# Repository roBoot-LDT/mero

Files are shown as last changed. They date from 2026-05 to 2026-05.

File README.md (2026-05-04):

# mero

A 45-day discipline project: build a remotely-controlled tracked/wheeled robot that finds 3 QR codes in camera view less than 2 minutes on uneven terrain

**Author:** Maksim Nemkov
**Started:** 2026-05-04
**Hard deadline:** 2026-06-17 (45 days)

---

## Why this project exists

This repository is not primarily a robotics project. It is a discipline experiment.

The goal is to complete one self-initiated technical project from start to finish, on time, with a publicly visible result. The robot is the medium, not the message. The message is: "I can finish what I start"

For three years prior to this project, no voluntary technical project was completed. This is the attempt to break that pattern. The project is intentionally constrained in scope so that the binding constraint is follow-through, not technical capability.

---

## What the robot does (Definition of Done)

A wheeled robot that:

1. Is controlled remotely over BLE from a custom 5-button pad (4 directions + start/stop).
2. Carries an ESP32-CAM that streams video over WiFi to a server.
3. The server detects QR codes in the video stream using OpenCV in real time.
4. The operator drives the robot on uneven terrain so that a pre-placed 3 QR codes must be founded and be inside the camera frame less than 2 minutes.

**The project is considered done when:**

- 5 out of 10 attempts succeed at founding the 3 QRs in frame less than 2 minutes on a defined uneven surface.
- All 10 attempts are recorded on video and published in this repository.
- A final write-up exists in `docs/postmortem.md` covering what worked, what didn't, what the next iteration would change.

**Not in scope for v1 (these belong to v2 if there ever is one):**

- Camera gimbal with servo stabilization
- Autonomous QR search
- Autonomous driving
- Obstacle avoidance
- Battery telemetry, OTA updates, app GUI

If during the 45 days the temptation arises to add any of the above, the rule is: **note it in `IDEAS.md` and do not implement it.**

---

## Architecture

Three independent nodes, intentionally separated to avoid one ESP32 trying to do everything.

```
+---------------------+        BLE 5         +-----------------------+
|  REMOTE             | <==================> |  ROBOT MAIN           |
|  ESP32 dev board    |                      |  ESP32-S3-N16R8       |
|  5 tactile buttons  |                      |  motor driver         |
|                     |                      |  (TB6612FNG / DRV8833)|
+---------------------+                      |  2x DC motors         |
                                             |  2x 18650 + BMS 2S    |
                                             |  buck 5V              |
                                             +-----------+-----------+
                                                         |
                                                         | WiFi (same AP)
                                                         |
                                             +-----------v-----------+
                                             |  ESP32-CAM            |
                                             |  MJPEG stream / HTTP  |
                                             +-----------+-----------+
                                                         |
                                                         | WiFi
                                                         |
                                             +-----------v-----------+
                                             |  SERVER (laptop or VPS)|
                                             |  Python + OpenCV       |
                                             |  pyzbar / cv2.QRCode   |
                                             |  publishes detection   |
                                             |  events                |
                                             +------------------------+
```

**Why three nodes and not one:** a single ESP32-CAM cannot reliably run BLE + WiFi + camera + motor PWM at the same time. It has too few free GPIOs after the camera takes its pins, and BLE/WiFi share the radio. Splitting responsibilities makes each node simpler and debuggable in isolation.

**Why the server and not on-device QR detection:** ESP32-CAM can do QR detection locally (`esp32-camera` + `quirc` works), but routing detection to a Python server gives a cleaner debugging surface, easier logging, and faster iteration on detection parameters during the 45 days. After the project is done, on-device detection is a candidate for v2.

---

## Hardware

| Component | Notes |
|---|---|
| ESP32-S3-N16R8 dev board | Robot main controller. BLE 5 + WiFi 4. |
| ESP32 (any DevKit) | Remote control unit. |
| ESP32-CAM | Video streaming over WiFi. |
| TB6612FNG or DRV8833 | Motor driver. **Not L293D** — it cannot handle the stall current of these motors. |
| 2x DC motors (RS-385 class, 5V nominal) | Drive motors. |
| 2x 18650 Li-Ion cells + 2S BMS | Robot power. ~7.4V nominal. |
| MP1584 or LM2596 buck converter | Steps 7.4V down to 5V for ESP32 / driver logic. |
| 5x tactile buttons + pull-ups | Remote keypad. |
| Wheels (printed) | Diameter ≥ 80 mm, otherwise robot is geared too fast. |
| 3D printer (Bambu Lab P1S) | Chassis, mounts, wheels. |
| Multimeter, soldering iron, lab PSU | Already on hand. |

**Critical caveats discovered before start:**

- ESP32-S3 supports BLE 5 only, **not** classic Bluetooth. The remote must speak BLE GATT.
- L293D is too weak for these motors and will burn out under stall load. Replaced with TB6612FNG / DRV8833.
- Bare DC motors without gearing rev too fast (5–15k RPM) and have low torque at low speed — large wheels or geared replacements are required for terrain.
- Two 18650 in series is 7.4V. Connecting that directly to a 3.3V or 5V logic input destroys the board. A buck converter is mandatory.

---

Long-form notes live in Obsidian. What lands in `docs/devlog.md` is the public summary, written at least once per week.

---

## Milestones

Three checkpoints. Each has a measurable, video-verifiable state. Missing a checkpoint by more than 3 days triggers a written re-plan in `docs/milestones.md`, not a silent slip.

### M1 — 2026-05-18 (day 15): bench integration

- Chassis printed and assembled (motors mounted, wheels on, can be held in hand).
- ESP32-S3 drives both motors forward / back / left / right via TB6612FNG over USB-serial commands. No BLE yet.
- ESP32-CAM streams MJPEG to laptop over WiFi.
- Python server pulls stream, runs `cv2.QRCodeDetector` (or `pyzbar`), logs `qr_seen=True/False` per frame.
- Video evidence: 30 seconds showing motors responding, stream live, QR detection logged.

### M2 — 2026-06-01 (day 30): wireless robot

- BLE remote control works. Robot drives untethered.
- Robot runs from 18650 + BMS + buck. No bench PSU.
- Video stream survives motion. QR detection still works on a moving feed.
- Robot drives reliably on flat indoor surface.
- Video evidence: 2 minutes of free driving, QR detected on the move.

### M3 — 2026-06-17 (day 45): final challenge

- Defined uneven test surface (photographed, dimensioned).
- 10 attempts at the 2-minute QR-hold task. All recorded.
- Postmortem written.
- README updated with results — pass or fail honestly.

If M3 succeeds: project is done.
If M3 fails: the project is **still done.** A failed-but-finished project beats an abandoned one. A failed run still gets written up and committed.

## License

MIT. See `LICENSE`.

---

## Contact

This is a solo project. Issues and PRs are not expected, but the repository is public so that finishing the project is a publicly visible commitment.

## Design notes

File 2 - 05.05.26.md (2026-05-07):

Начал собирать схему - спаял коннекторы к движкам, подсоединил их к плате l298n, подключил батарейный отсек. Соединил проводами по datasheet esp32 и l298n для управления движками. 
Спаял с флюсом и припоем (движки) - поверх добавил термоклея для надежности.
Плату esp32 буду питать от лабораторника.
Важное уточнение - на данный момент блок с 18650 подключен напрямую и не имеет между собой схему со вчерашнего дня, к ней я перейду позже.
Дополнительно ко всему - загрузил программу для тестирования работы движков. Получилось успешно - итог 2го дня на видео [[day2_vid.MOV]].

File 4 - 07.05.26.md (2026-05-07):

Сегодня главная задача - подсоединить БП к электросхеме и создать платформу на которой будут находиться все компоненты.

Припаял MP1584 (регулятор напряжения), изначально выход был 5.7в, с помощью потенциометра на плате понизил до 5в.
Включил - работает. Видео [[day4_vid.MOV]]

На будущее - возможно при пайке контактов p+ p- hx-2s-d20 он включает свою защиту и приходится его "будить" обратной подачей напряжения.

DONE:
- MP1584 buck настроен на 5V, подтверждено мультиметром
- ESP32-S3 питается автономно от блока питания через MP1584
- L298N питается от P+/P− BMS (7.4V)
- Прошивка загружена, моторы выполняют цикл forward/back/left/right
- Первый автономный запуск без USB и лабораторного БП — работает

Спустя пару часов - сделал большой прогресс: подключил камеру esp32-cam, прошил с помощью pl2303 USB UART boada. Конечно пришлось попотеть чтобы банально "зафлэшить" софт на esp32 из-за особенностей платы (нужно замкнуть gnd i0) и потом еще потратить время чтобы понять: для первичного запуска софта нужно нажать кнопку hard reset... 
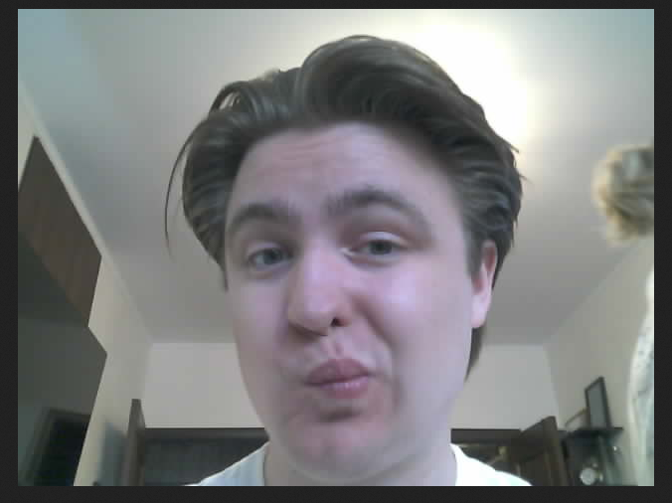
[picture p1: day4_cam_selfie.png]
По итогу - получилось сделать селфи: 

Далее - сделал так чтобы камера отсылала видеопоток на локальный сервер. Потом смогу обрабатывать видео и искать на нем Qr
Написал код для получения данных с сервера и сканирования на наличие qr.
Успех! Вот только не стабильно сканируется QR на камере, но надеюсь это поправимо

Сделаю коммит и пойду дальше - так как уже с точки зрения схемотехники все закончено (на роботе). Следующая задача - создать платформу на которой все будет крепиться и красиво распаять все это на плате
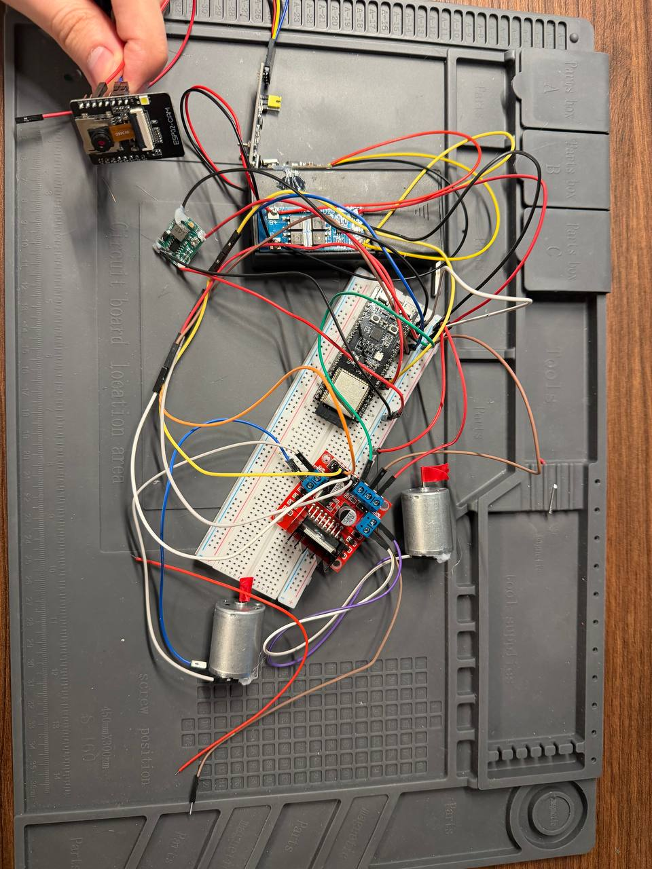
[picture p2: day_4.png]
Как это выглядит сейчас:

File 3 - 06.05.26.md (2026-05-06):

День 3. Сегодня я сделаю полноценно рабочий блок-питания для робота из:
- 2 банки 18650
- Регулятора зарядки\разрядки HX-2S-D20
- Регулятора зарядки с TYPE-C BMS 2S
- Корпуса для 2 банок
Соединил в единый компонент. В данный момент проверяю, все ли корректно. Подключил type-c и на LX-USC-V2 начал гореть светодиод, в видео где его использовали - было также. При отключении тумблера на холдере - светодиод начинает мигать. Надеюсь это признак "рабочисти" всей схемы. Замерил напряжение на p+ p- - 1.82в. Как-то очень мало для 2 новых банок и по идее это означает что они трупы. Но дам еще времени зарядиться и проверю напряжение вновь

DONE: 
- Собран блок питания: 2x18650 + HX-2S-D20 BMS + LX-USC-V2 зарядка 
- BMS сбрасывается подачей 8.5V на P+/P− от лабораторного БП 
- Выход P+/P−: 7.4V подтверждено мультиметром 
PROBLEMS:
- LX-USC-V2 нагрелся при первом подключении (термоклей расплавился) 
- BMS заблокировал выход при первом включении → сброс: 8.5V на P+/P− от лабораторного БП на 5-10 секунд
LEARNED: 
- BMS серии HX-2S разблокируется подачей зарядного напряжения на P+/P−

Доп - очень тяжело паялась клемма в холдере (для подключения BM), пришлось накрутить провод на клемму и зафиксировать термоклеем.

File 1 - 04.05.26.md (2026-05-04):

Начал составлять схему подключения всех компонентов
На этом этапе начал разбираться с работой каждого комплектующего: L298N, bms 2s, mp1584 и прочее
Около часа капался в datasheet'ах каждого элемента для корректного подключения (на бумаге)
В моменте проектирования стало понятно что просто использовать 2 банки 18650 напрямую в l298n и отдельную банку на контроллер esp32 - не логично, можно параллельно соединить и l298n и esp32, вот только при подаче напряжения 7,2V на esp32 - будет kaputt. Потому между ними добавляю mp1584 с выходом на 5В

Во время уточнения работы с 18650, с помощью BMS, оказалось что был куплен charging controller, а не charge/discharge. Докупил HX-2S-D20 - будет завтра. BMS 2S выбрасывать не буду, так как на плате есть usb type-c с помощью которого зарядка банок будет удобна. В электро-схему добавил уточнение в компоновку питания. Фото и набросок прикладываю.

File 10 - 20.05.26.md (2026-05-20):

День 10
Вчерашняя проблема с потерей подключения при нажатии любой кнопки - вылечена. 
Во время работы выяснилась другая проблема - при добавлении регулятора AMS1117 3.3V - плата работала не стабильно и банально не запускалась
Вероятнее всего проблема в падении напряжения при включении bluetooth. Эту закономерность смог отследить наличием светодиода состояния работы платы
Пробовал припаять параллельно 2 конденсатора на 20мкф суммарно, но не помогло...
По итогу удалил из цепи ams1117 и подключил питание напрямую в VIN. Заработало. 
Важное уточнение: во время одного из тестов пульт управления не запустился и была таже проблема что и ранее
Выключив и включив - проблема прошла. Возможное решение - добавить больший конденсатор.
Также инвертировал направление поворотов робота и перевернул камеру на 180
Задача на следующий день - отрегулировать плавность движения робота. И попробовать отсканировать QR в первый раз с помощью удаленного управления

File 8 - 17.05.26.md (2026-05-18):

День 8. Был большой перерыв между обновлениями - все никак не получалось соединить робота с контроллером по bluetooth. 
После печати 3д модели выявлены следующие нюансы:
 - Нужно переделать положение двигателей (сделать их ближе к корпусу)
 - Допуска в диаметре шин и колеса нужно уменьшить. Шина получилась неровной
 - Нужно каким-либо образом сделать автоцентрирование шины на колесе
 - Включение\выключение блока питания нужно вывести отдельно, в удобное место
 - Нужно выровнять колесо-роллер, чтобы робот был выровнен по горизонтали
 - Продумать отладку и подключение micro-usb к esp32s3 робота, когда плата уже подсоединена к корпусу
 - Повысить плату над корпусом, так как в данный момент ножки esp32s3 упираются в корпус
 - Требуется продумать регулировку уровня наклона платы камеры с помощью физического взаимодействия
 - Создать крышку для робота

Фото сборки в данный момент прилагаю:
![[day8_robot.png]]

Проблемы во время разработки:
 - Моторы не корректно работали, при одних и техже значениях - моторы крутятся по разному. Это оказалось из-за логики работы L298N. Прозвонил все пины ведущие к l298n и оказалось что 1 пин не пропаял, исправил и все получилось

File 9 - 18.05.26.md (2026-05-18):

День 9
За сегодняшний день собрал контроллер дистанционного управления роботом. Пайка занимает уйму времени. Помимо этого, конечно же, все работает не с первого раза. Сегодня не было исключения и к концу дня - у контроллера работает только кнопка "вперед". Оно и правильно - куда еще, если не вперед
Помимо этого при нажатии на кнопку вперед - контроллер сразу теряет связь с роботом...
Завтра буду решать эту проблему
И еще - припаял питание к esp32-cam. Факт на будущее - у этой платы нет светодиода уведомления о работе (потратил 20 минут времени на выяснение того, что плата уже работала)
Фото-отчет за сегодня:
![[day9_controller.png]]
![[day9_full_build.png]]

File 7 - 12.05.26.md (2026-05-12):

День 7. Чутка доделал 3д модель и отправил на печать. 6 часов заняла печать сразу:
- корпуса
- 2 держателей двигателя
- 2 диска
На удивление получилось хорошо. Нужно будет отредактировать напильником или гравером, но лишь 1мм у держателя двигателя. Во всем остальном пока подходит.
![[day7_printables.png]]
Завтра подсоединю электросхему, закреплю двигатели, батарею и поставлю на печать шины

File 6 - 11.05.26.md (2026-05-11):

Сегодня сделал 3д модель:
- Несущего корпуса
- Держателей двигателей
- Шины
- Резины
- Двигателей
- Ролика
Заранее предусмотрел крепежные отверстия вместе с отверстиями для проводов. Завтра чуть отредактирую скругления и начну печатать. 
![[day6_assembly.png]]

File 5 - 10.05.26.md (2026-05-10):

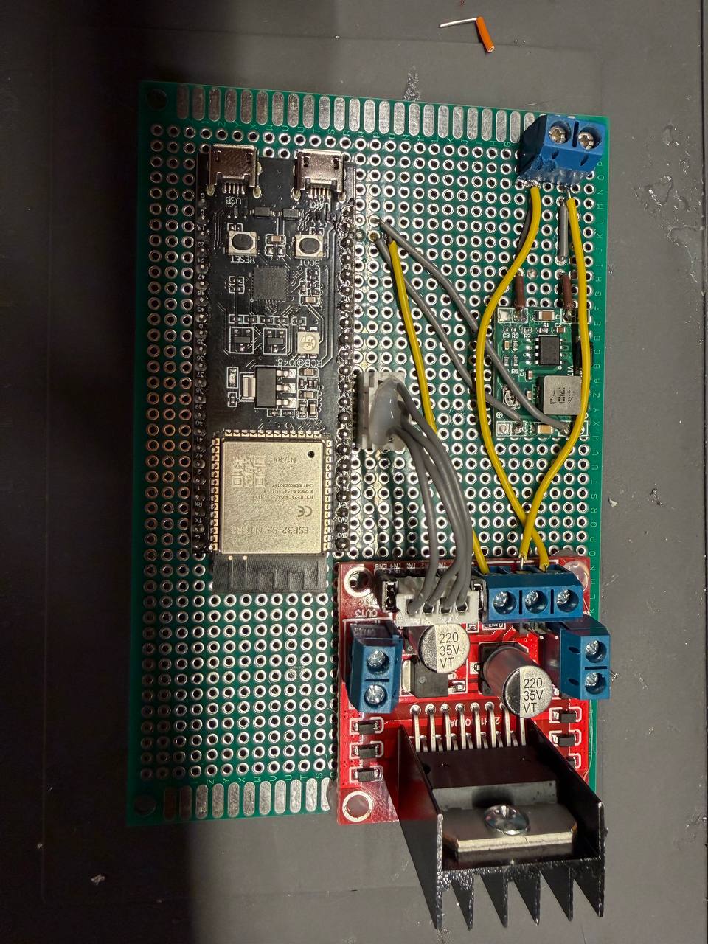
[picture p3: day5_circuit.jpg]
За сегодняшний день (после Майских праздников) я смог улучшить мою схему вместе в моторами. Распаял все компоненты на зеленой платформе с новыми коммутациями и удобным подключением. Это заняло очень много времени и я надеюсь это стоило того. Ну и в конце-концов это работает: 

![[day5_circuit2.png]]

Также про двигатели - нашел в закромах старые движки с древнего проекта. Это абсолютно такие-же двигатели как и были, только с редуктором. Взял их, припаял провода, укрепил термоусадкой.
Я доволен проделанной работой.
Завтра начну делать 3д модель корпуса. Заранее размышляю о механической регулировке угла наклона камеры.

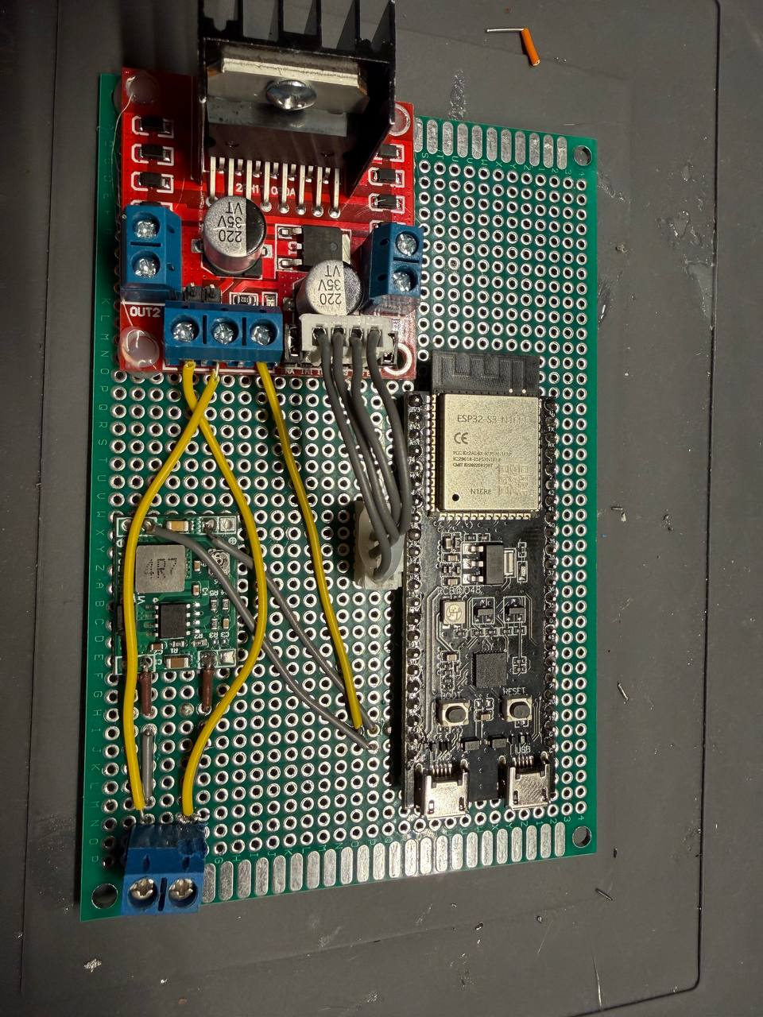
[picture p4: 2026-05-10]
day5_circuit2.png

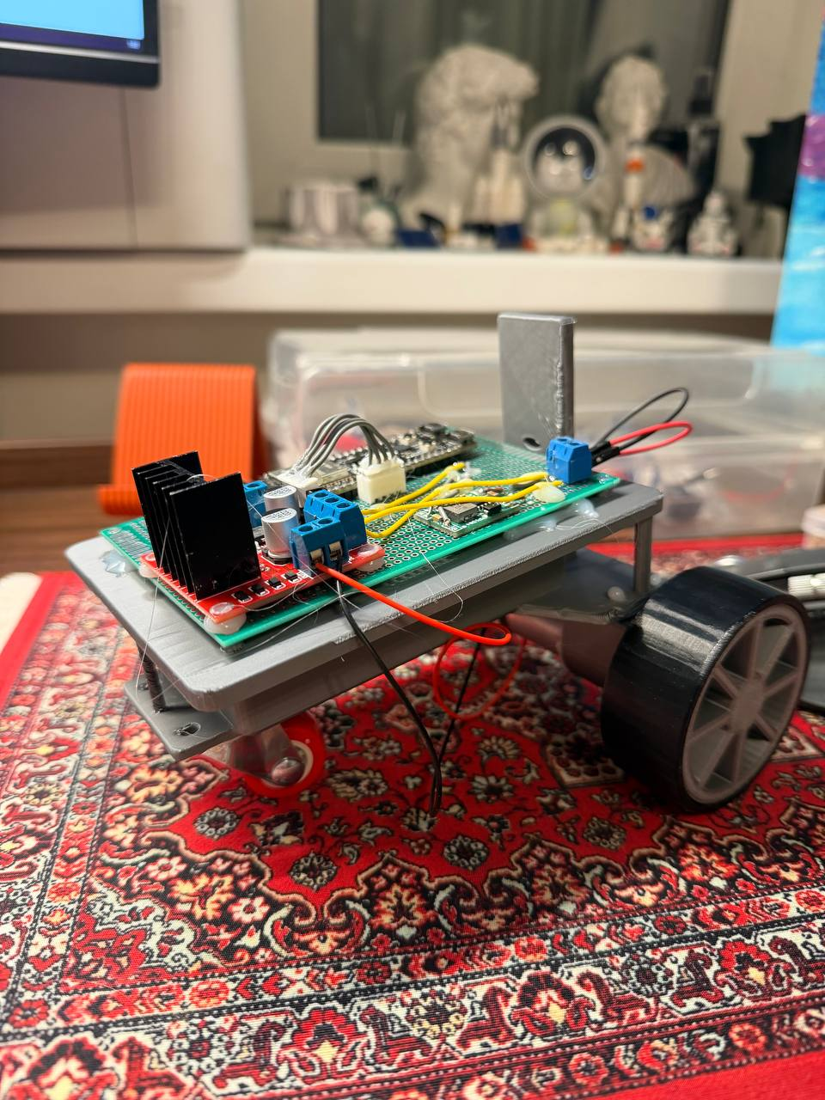
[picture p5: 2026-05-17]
day8_robot.png

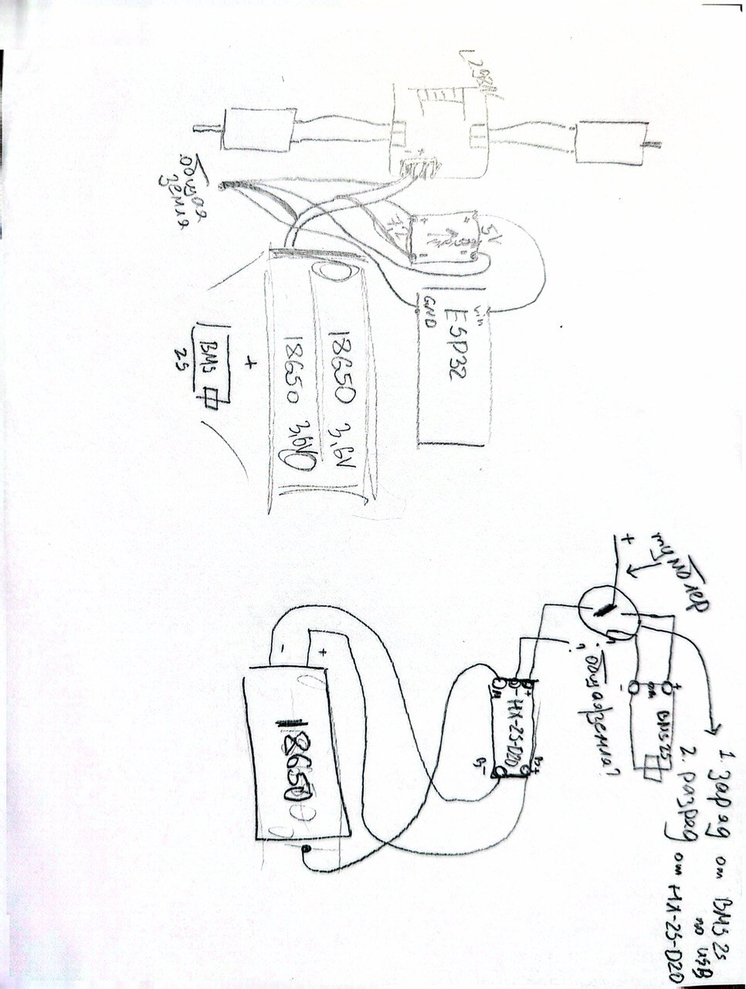
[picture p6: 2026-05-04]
image.png

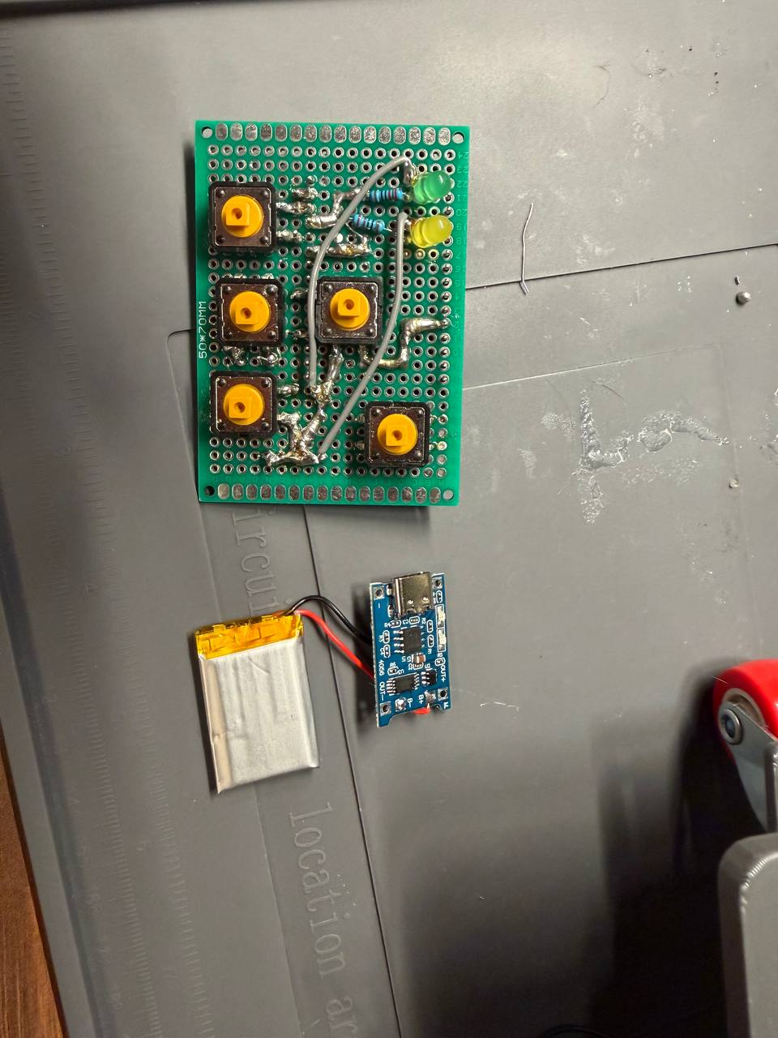
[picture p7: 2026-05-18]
day9_controller.png

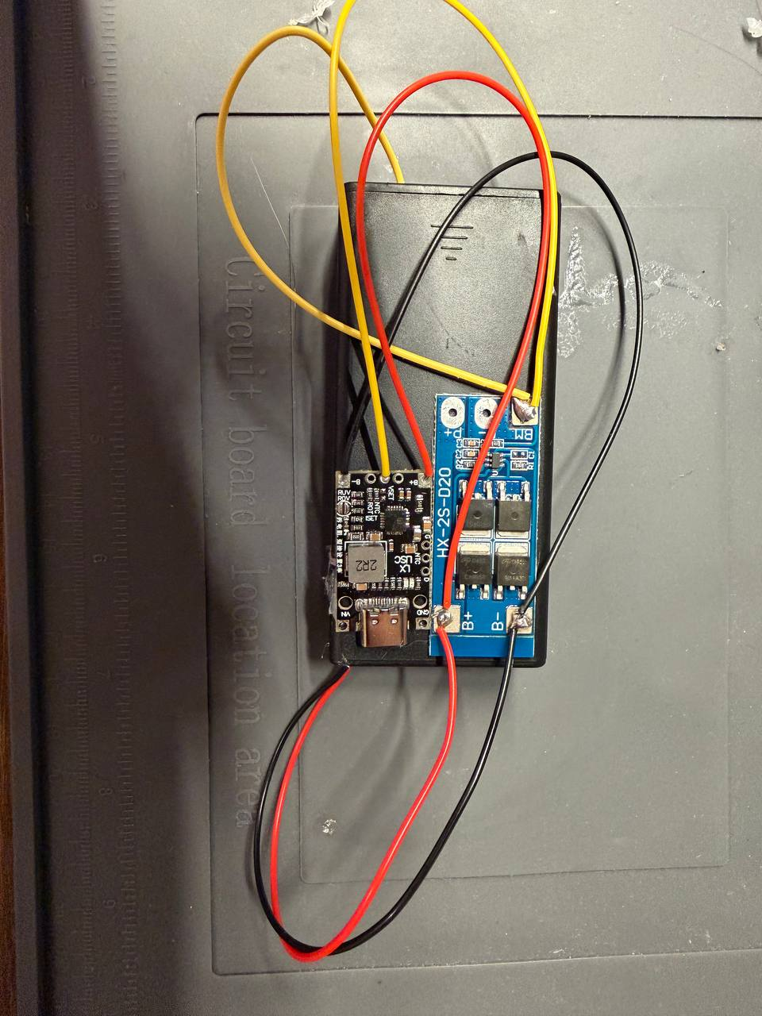
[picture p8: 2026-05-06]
power_unit.png

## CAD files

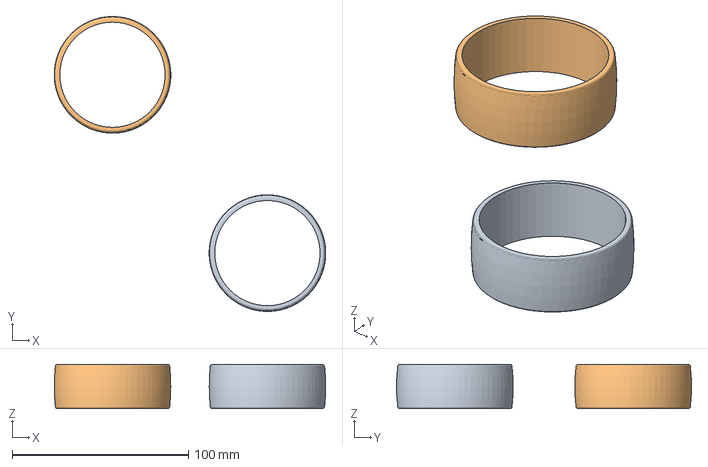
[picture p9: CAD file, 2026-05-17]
3d_parts/rubber.3mf
154.2 x 167.6 x 25.0 mm
rubber.stl x 2

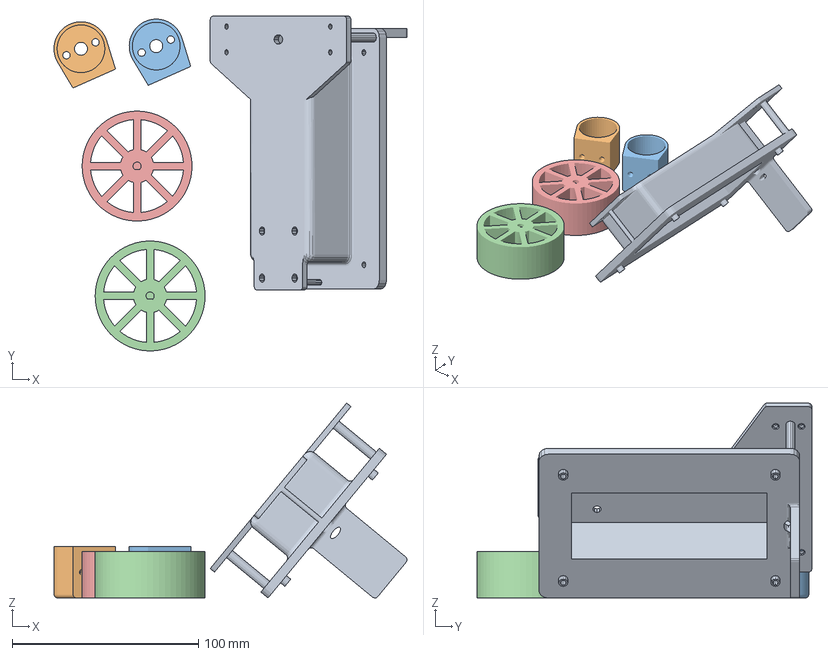
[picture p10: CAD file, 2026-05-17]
3d_parts/body.3mf
189.5 x 179.7 x 104.7 mm
body.stl
motor_holder.stl x 2
wheel.stl x 2

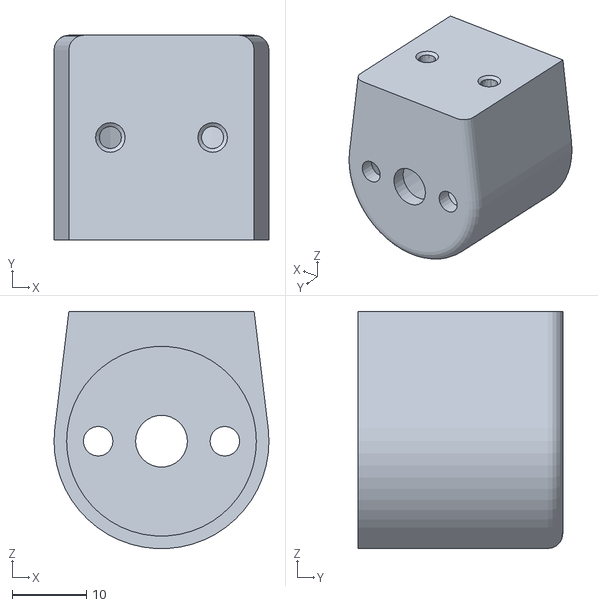
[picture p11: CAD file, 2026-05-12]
3d_parts/motor_holder.stl
29.0 x 27.6 x 32.0

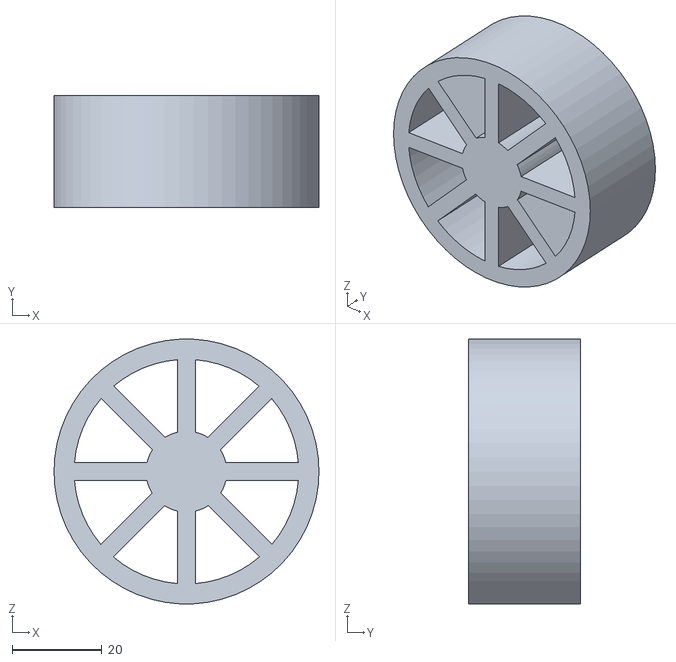
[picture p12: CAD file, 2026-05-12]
3d_parts/wheel.stl
59.0 x 25.0 x 58.9

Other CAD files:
3d_parts/Assembly.iam
3d_parts/OldVersions/Assembly.0002.iam
3d_parts/OldVersions/body.0003.ipt
3d_parts/OldVersions/dc12v1200rpm.0001.ipt
3d_parts/OldVersions/motor_holder.0001.ipt
3d_parts/OldVersions/roller.0003.ipt
3d_parts/OldVersions/wheel.0001.ipt
3d_parts/body.ipt
3d_parts/body.stl
3d_parts/dc12v1200rpm.ipt
3d_parts/disk.ipt
3d_parts/motor_holder.ipt
3d_parts/roller.ipt
3d_parts/rubber.ipt
3d_parts/rubber.stl
3d_parts/wheel.iam
3d_parts/wheel.ipt

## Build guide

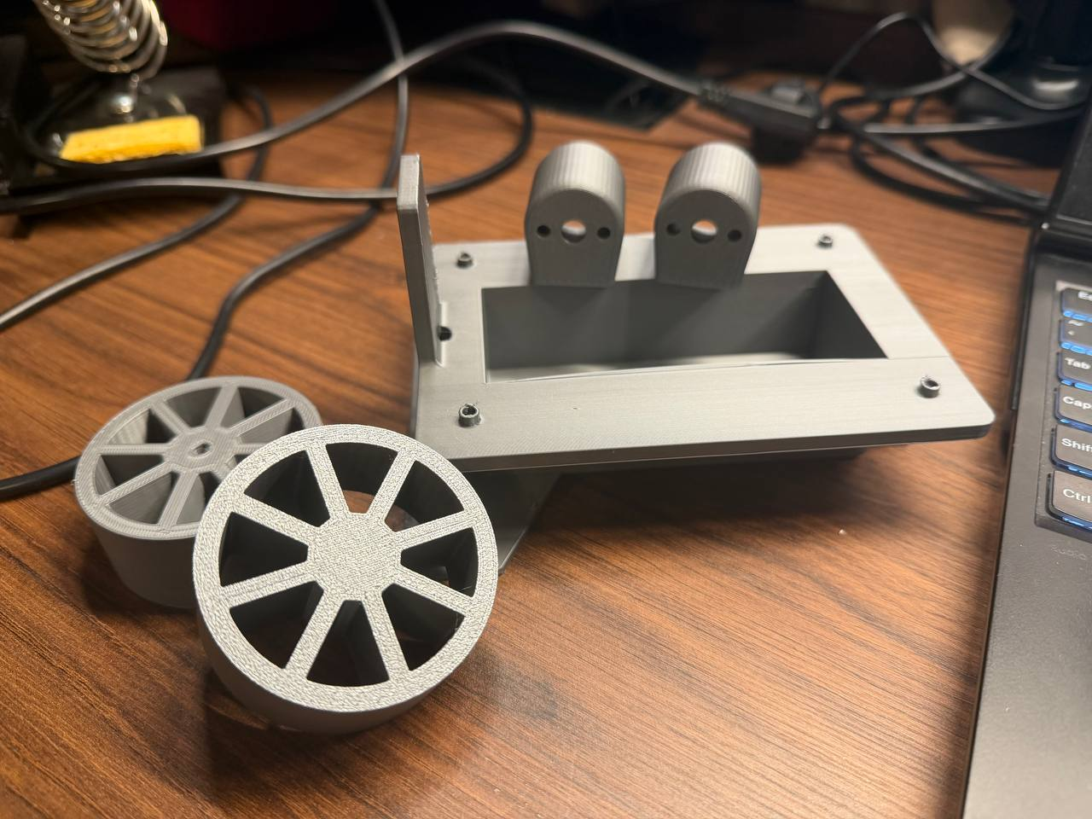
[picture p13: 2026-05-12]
day7_printables.png

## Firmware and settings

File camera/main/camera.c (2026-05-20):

#include <stdio.h>
#include <string.h>
#include "freertos/FreeRTOS.h"
#include "freertos/task.h"
#include "esp_log.h"
#include "esp_wifi.h"
#include "esp_event.h"
#include "nvs_flash.h"
#include "esp_http_server.h"
#include "esp_camera.h"

static const char *TAG = "mero-cam";

// --- Замени на свои данные ---
#define WIFI_SSID "MALADESH"
#define WIFI_PASS "b2314g392sbb"
// ----------------------------

// AI-Thinker ESP32-CAM + OV3660 pinout
#define CAM_PIN_PWDN    32
#define CAM_PIN_RESET   -1
#define CAM_PIN_XCLK     0
#define CAM_PIN_SIOD    26
#define CAM_PIN_SIOC    27
#define CAM_PIN_D7      35
#define CAM_PIN_D6      34
#define CAM_PIN_D5      39
#define CAM_PIN_D4      36
#define CAM_PIN_D3      21
#define CAM_PIN_D2      19
#define CAM_PIN_D1      18
#define CAM_PIN_D0       5
#define CAM_PIN_VSYNC   25
#define CAM_PIN_HREF    23
#define CAM_PIN_PCLK    22

static esp_err_t camera_init(void) {
    camera_config_t config = {
        .pin_pwdn     = CAM_PIN_PWDN,
        .pin_reset    = CAM_PIN_RESET,
        .pin_xclk     = CAM_PIN_XCLK,
        .pin_sccb_sda = CAM_PIN_SIOD,
        .pin_sccb_scl = CAM_PIN_SIOC,
        .pin_d7 = CAM_PIN_D7, .pin_d6 = CAM_PIN_D6,
        .pin_d5 = CAM_PIN_D5, .pin_d4 = CAM_PIN_D4,
        .pin_d3 = CAM_PIN_D3, .pin_d2 = CAM_PIN_D2,
        .pin_d1 = CAM_PIN_D1, .pin_d0 = CAM_PIN_D0,
        .pin_vsync = CAM_PIN_VSYNC,
        .pin_href  = CAM_PIN_HREF,
        .pin_pclk  = CAM_PIN_PCLK,
        .xclk_freq_hz = 20000000,
        .ledc_timer   = LEDC_TIMER_0,
        .ledc_channel = LEDC_CHANNEL_0,
        .pixel_format = PIXFORMAT_JPEG,
        .frame_size   = FRAMESIZE_VGA,   // 640x480
        .jpeg_quality = 12,              // 0-63, меньше = лучше качество
        .fb_count     = 2,
        .grab_mode    = CAMERA_GRAB_WHEN_EMPTY,
    };
    esp_err_t err = esp_camera_init(&config);
    if (err != ESP_OK) {
        ESP_LOGE(TAG, "Camera init failed: 0x%x", err);
    }
    return err;
}

// MJPEG stream handler
static esp_err_t stream_handler(httpd_req_t *req) {
    camera_fb_t *fb = NULL;
    esp_err_t res = ESP_OK;
    char part_buf[64];

    res = httpd_resp_set_type(req,
        "multipart/x-mixed-replace;boundary=frame");
    if (res != ESP_OK) return res;

    while (true) {
        fb = esp_camera_fb_get();
        if (!fb) {
            ESP_LOGE(TAG, "Camera capture failed");
            res = ESP_FAIL;
            break;
        }

        // boundary
        size_t hlen = snprintf(part_buf, sizeof(part_buf),
            "--frame\r\nContent-Type: image/jpeg\r\n"
            "Content-Length: %zu\r\n\r\n", fb->len);
        res = httpd_resp_send_chunk(req, part_buf, hlen);
        if (res == ESP_OK)
            res = httpd_resp_send_chunk(req,
                (const char *)fb->buf, fb->len);
        if (res == ESP_OK)
            res = httpd_resp_send_chunk(req, "\r\n", 2);

        esp_camera_fb_return(fb);
        if (res != ESP_OK) break;
    }
    return res;
}

static httpd_handle_t start_webserver(void) {
    httpd_config_t config = HTTPD_DEFAULT_CONFIG();
    config.server_port = 80;
    httpd_handle_t server = NULL;
    if (httpd_start(&server, &config) != ESP_OK) return NULL;

    httpd_uri_t stream_uri = {
        .uri      = "/stream",
        .method   = HTTP_GET,
        .handler  = stream_handler,
    };
    httpd_register_uri_handler(server, &stream_uri);
    ESP_LOGI(TAG, "Stream ready at http://<IP>/stream");
    return server;
}

static void wifi_event_handler(void *arg, esp_event_base_t base,
                               int32_t id, void *data) {
    if (base == WIFI_EVENT && id == WIFI_EVENT_STA_START)
        esp_wifi_connect();
    else if (base == IP_EVENT && id == IP_EVENT_STA_GOT_IP) {
        ip_event_got_ip_t *e = (ip_event_got_ip_t *)data;
        ESP_LOGI(TAG, "IP: " IPSTR, IP2STR(&e->ip_info.ip));
        start_webserver();
    } else if (base == WIFI_EVENT && id == WIFI_EVENT_STA_DISCONNECTED) {
        ESP_LOGW(TAG, "WiFi disconnected, retrying...");
        esp_wifi_connect();
    }
}

static void wifi_init(void) {
    ESP_ERROR_CHECK(esp_netif_init());
    ESP_ERROR_CHECK(esp_event_loop_create_default());
    esp_netif_create_default_wifi_sta();

    wifi_init_config_t cfg = WIFI_INIT_CONFIG_DEFAULT();
    ESP_ERROR_CHECK(esp_wifi_init(&cfg));

    ESP_ERROR_CHECK(esp_event_handler_register(
        WIFI_EVENT, ESP_EVENT_ANY_ID, wifi_event_handler, NULL));
    ESP_ERROR_CHECK(esp_event_handler_register(
        IP_EVENT, IP_EVENT_STA_GOT_IP, wifi_event_handler, NULL));

    wifi_config_t wifi_cfg = {
        .sta = {
            .ssid     = WIFI_SSID,
            .password = WIFI_PASS,
        },
    };
    ESP_ERROR_CHECK(esp_wifi_set_mode(WIFI_MODE_STA));
    ESP_ERROR_CHECK(esp_wifi_set_config(WIFI_IF_STA, &wifi_cfg));
    ESP_ERROR_CHECK(esp_wifi_start());
}

void app_main(void) {
    ESP_LOGI(TAG, "boot");
    ESP_ERROR_CHECK(nvs_flash_init());
    
    if (camera_init() != ESP_OK) {
        ESP_LOGE(TAG, "Camera failed, halting");
        return;
    }

    sensor_t *s = esp_camera_sensor_get();
    if (s != NULL) {
        s->set_vflip(s, 1);
        s->set_hmirror(s, 1);
    }
    wifi_init();
    ESP_LOGI(TAG, "Waiting for WiFi...");
}

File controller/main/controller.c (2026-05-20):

#include <stdio.h>
#include <string.h>
#include "freertos/FreeRTOS.h"
#include "freertos/task.h"
#include "driver/gpio.h"
#include "esp_log.h"
#include "nvs_flash.h"
#include "nimble/nimble_port.h"
#include "nimble/nimble_port_freertos.h"
#include "host/ble_hs.h"
#include "host/util/util.h"

static const char *TAG = "mero-remote";

#define BTN_FORWARD  GPIO_NUM_21
#define BTN_BACK     GPIO_NUM_15
#define BTN_LEFT     GPIO_NUM_13
#define BTN_RIGHT    GPIO_NUM_33
#define BTN_STOP     GPIO_NUM_17

// Светодиоды
#define LED_POWER    GPIO_NUM_12   // горит всегда когда включён
#define LED_SEND     GPIO_NUM_27  // мигает при отправке команды

#define ROBOT_NAME   "mero-robot"

static const ble_uuid128_t cmd_svc_uuid =
    BLE_UUID128_INIT(0x12,0x34,0x56,0x78,0x12,0x34,0x12,0x34,
                     0x12,0x34,0x12,0x34,0x12,0x34,0x56,0x78);

static uint8_t own_addr_type;
static uint16_t conn_handle = BLE_HS_CONN_HANDLE_NONE;
static uint16_t cmd_attr_handle = 0;
static bool connected = false;

static void start_scan(void);
static int gap_event(struct ble_gap_event *event, void *arg);

static void leds_init(void) {
    gpio_config_t cfg = {
        .pin_bit_mask = (1ULL << LED_POWER) | (1ULL << LED_SEND),
        .mode = GPIO_MODE_OUTPUT,
        .pull_up_en = GPIO_PULLUP_DISABLE,
        .pull_down_en = GPIO_PULLDOWN_DISABLE,
        .intr_type = GPIO_INTR_DISABLE,
    };
    gpio_config(&cfg);
    gpio_set_level(LED_POWER, 1);  // сразу включаем
    gpio_set_level(LED_SEND, 0);
}

// static int on_write(uint16_t conn_h, const struct ble_gatt_error *error,
//                     struct ble_gatt_attr *attr, void *arg) {
//     if (error->status != 0)
//         ESP_LOGE(TAG, "write failed: %d", error->status);
//     return 0;
// }

static void send_cmd(char c) {
    if (!connected || cmd_attr_handle == 0) return;
    if (conn_handle == BLE_HS_CONN_HANDLE_NONE) return;
    
    int rc = ble_gattc_write_no_rsp_flat(conn_handle, cmd_attr_handle, &c, 1);
    if (rc != 0) {
        ESP_LOGW(TAG, "write skipped: %d", rc);
    }
}

static void buttons_init(void) {
    gpio_config_t cfg = {
        .pin_bit_mask = (1ULL<<BTN_FORWARD)|(1ULL<<BTN_BACK)|
                        (1ULL<<BTN_LEFT)|(1ULL<<BTN_RIGHT)|(1ULL<<BTN_STOP),
        .mode = GPIO_MODE_INPUT,
        .pull_up_en = GPIO_PULLUP_ENABLE,
        .pull_down_en = GPIO_PULLDOWN_DISABLE,
        .intr_type = GPIO_INTR_DISABLE,
    };
    gpio_config(&cfg);
}

static char last_cmd = 's';

static void buttons_task(void *arg) {
    while (1) {
        char cmd = 0;
        if      (!gpio_get_level(BTN_FORWARD)) cmd = 'f';
        else if (!gpio_get_level(BTN_BACK))    cmd = 'b';
        else if (!gpio_get_level(BTN_LEFT))    cmd = 'l';
        else if (!gpio_get_level(BTN_RIGHT))   cmd = 'r';
        else if (!gpio_get_level(BTN_STOP))    cmd = 's';
        else                                   cmd = 's';

        if (cmd != last_cmd) {
            last_cmd = cmd;
            send_cmd(cmd);
            ESP_LOGI(TAG, "cmd: %c", cmd);
            vTaskDelay(pdMS_TO_TICKS(50)); 
        }
        vTaskDelay(pdMS_TO_TICKS(50));
    }
}

static int on_disc_chr(uint16_t conn_h, const struct ble_gatt_error *error,
                       const struct ble_gatt_chr *chr, void *arg) {
    if (error->status == 0 && chr) {
        if ((chr->properties & BLE_GATT_CHR_F_WRITE) ||
            (chr->properties & BLE_GATT_CHR_F_WRITE_NO_RSP)) {
            if (cmd_attr_handle == 0) {
                cmd_attr_handle = chr->val_handle;
                ESP_LOGI(TAG, "writable characteristic found, handle=%d",
                         cmd_attr_handle);
                connected = true;
                // Мигнуть LED_SEND 3 раза — сигнал успешного подключения
                for (int i = 0; i < 3; i++) {
                    gpio_set_level(LED_SEND, 1);
                    vTaskDelay(pdMS_TO_TICKS(100));
                    gpio_set_level(LED_SEND, 0);
                    vTaskDelay(pdMS_TO_TICKS(100));
                }
            }
        }
    }
    return 0;
}

static int on_disc_svc(uint16_t conn_h, const struct ble_gatt_error *error,
                       const struct ble_gatt_svc *svc, void *arg) {
    if (error->status == 0 && svc) {
        if (ble_uuid_cmp(&svc->uuid.u, &cmd_svc_uuid.u) == 0) {
            ESP_LOGI(TAG, "found cmd service, discovering characteristics...");
            ble_gattc_disc_all_chrs(conn_h, svc->start_handle,
                                    svc->end_handle, on_disc_chr, NULL);
        }
    }
    return 0;
}

static void start_scan(void) {
    struct ble_gap_disc_params disc_params = {
        .itvl = 0,
        .window = 0,
        .filter_policy = 0,
        .limited = 0,
        .passive = 0,
        .filter_duplicates = 1,
    };
    ble_gap_disc(own_addr_type, BLE_HS_FOREVER, &disc_params, gap_event, NULL);
}

static int gap_event(struct ble_gap_event *event, void *arg) {
    switch (event->type) {
    case BLE_GAP_EVENT_DISC: {
        struct ble_hs_adv_fields fields;
        ble_hs_adv_parse_fields(&fields, event->disc.data,
                                event->disc.length_data);
        if (fields.name && fields.name_len == strlen(ROBOT_NAME) &&
            memcmp(fields.name, ROBOT_NAME, fields.name_len) == 0) {
            ESP_LOGI(TAG, "found mero-robot, connecting...");
            ble_gap_disc_cancel();
            struct ble_gap_conn_params conn_params = {
                .scan_itvl           = 16,
                .scan_window         = 16,
                .itvl_min            = 24,
                .itvl_max            = 40,
                .latency             = 0,
                .supervision_timeout = 800,
                .min_ce_len          = 0,
                .max_ce_len          = 0,
            };
            ble_gap_connect(own_addr_type, &event->disc.addr,
                           5000, &conn_params, gap_event, NULL);
        }
        break;
    }
    case BLE_GAP_EVENT_CONNECT:
        if (event->connect.status == 0) {
            conn_handle = event->connect.conn_handle;
            ESP_LOGI(TAG, "connected");
            ble_gattc_disc_all_svcs(conn_handle, on_disc_svc, NULL);
        } else {
            ESP_LOGE(TAG, "connect failed, scanning again");
            start_scan();
        }
        break;
    case BLE_GAP_EVENT_DISCONNECT:
        connected = false;
        cmd_attr_handle = 0;
        conn_handle = BLE_HS_CONN_HANDLE_NONE;
        ESP_LOGW(TAG, "disconnected, scanning again");
        // Быстро мигнуть — сигнал потери связи
        for (int i = 0; i < 5; i++) {
            gpio_set_level(LED_SEND, 1);
            vTaskDelay(pdMS_TO_TICKS(50));
            gpio_set_level(LED_SEND, 0);
            vTaskDelay(pdMS_TO_TICKS(50));
        }
        start_scan();
        break;
    default: break;
    }
    return 0;
}

static void on_sync(void) {
    ble_hs_id_infer_auto(0, &own_addr_type);
    ESP_LOGI(TAG, "scanning for mero-robot...");
    start_scan();
}
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

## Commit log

2026-05-04 Day 1 - made the draft of the circuit board with some problem solving.
2026-05-05 Made the big update - connected l298n and esp32, motors and power unit. Additionally made the simple code to test the motors usage.
2026-05-05 Made the big update. Connected the l298n with esp32. Added motors. Power unit. And added the code to test the motors.
2026-05-06 Assembled and tested the power unit
2026-05-07 Day 4. Made the huge leap in progress. Already made the skeleton of the bot. The circuit looks like finished in general for experimental, now it should be solid and made on the good board.
2026-05-10 Re-do the circuit board on the green one. Took a long time, but that was worth it
2026-05-11 Day 6. Made the 3d model of the robot, at day 7 will print first version.
    [Assembly.iam, body.0002.ipt, body.ipt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]
2026-05-12 Day 7. Printed the parts
    [Assembly.0002.iam, Assembly.iam, body.0002.ipt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]
2026-05-17 Day 8. Assembled the bot. Wrote down some future fixes.
    [body.3mf, rubber.3mf, rubber.stl]
2026-05-18 Day 9. Re-done the controller. Eventually with the mistakes. Additional work needed
    [controller.c, robot.c]
2026-05-20 Day 10. Solved the controller issue. Updated the camera angle and the motors rotation angle. Soldered the power bank to the controller and solved the voltage problem
    [camera.c, controller.c, robot.c]
